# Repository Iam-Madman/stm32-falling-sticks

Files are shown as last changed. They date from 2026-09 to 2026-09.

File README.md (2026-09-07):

# stm32-falling-sticks

A DIY reaction-based "falling sticks" game controller built around an STM32 Bluepill.

## Features

- **STM32 Bluepill** as the main controller
- **10x electromagnet drivers (12v)** — MOSFET-switched, each with a flyback protection diode and pulldown resistor
- **10x Hall effect sensors (5v)** for stick drop/position detection
- **LCD output** support for game status/score
- **Buzzer (12v)** support, driven off the same MOSFET channels as the electromagnets
- **Start button** input to trigger the game
- **Single-layer PCB** — 0-ohm jumper resistors used in place of vias/second layer for a few connections
- **CNC-mill optimized** trace layout (tested on a Wegstr 3-axis CNC)

## Power

- Dual 12V input options: screw terminal or DC jack
- **MP1584EN buck converter** steps 12V down to 5V to power the electromagnets, Hall effect sensors, and Bluepill

## Board Previews

| View | Image |
| --- | --- |
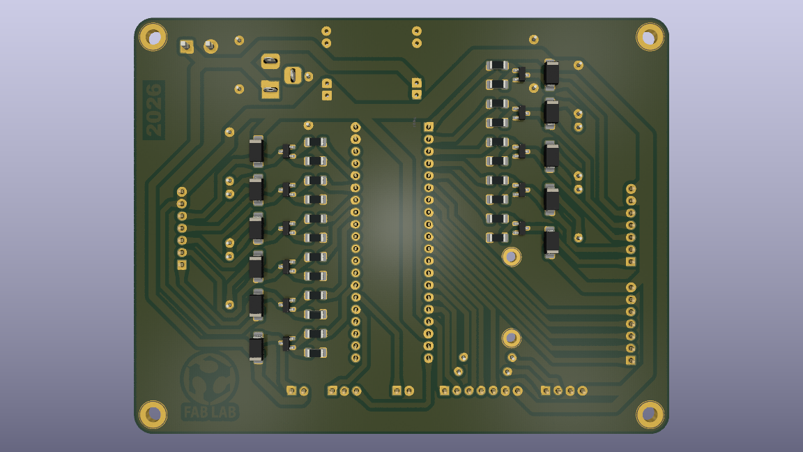
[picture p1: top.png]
Top View
| **Top View** |  |
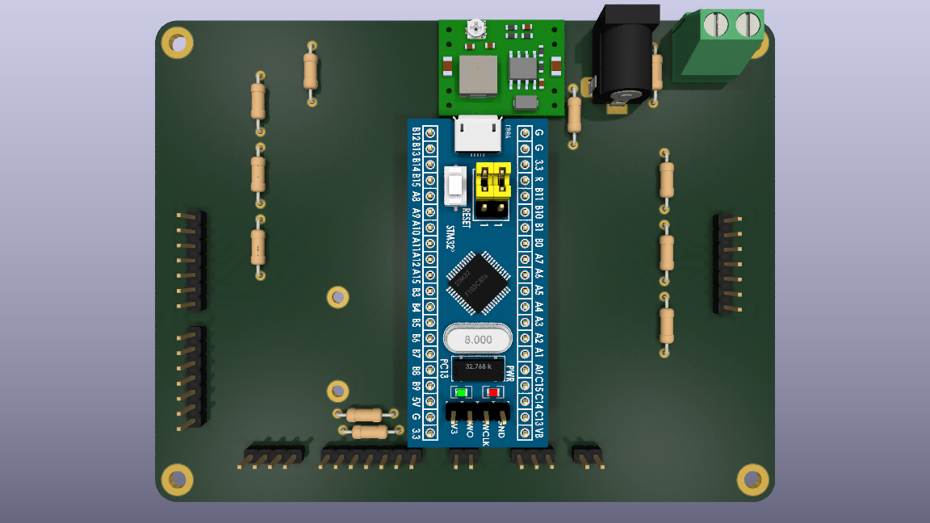
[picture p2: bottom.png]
Bottom View
| **Bottom View** |  |
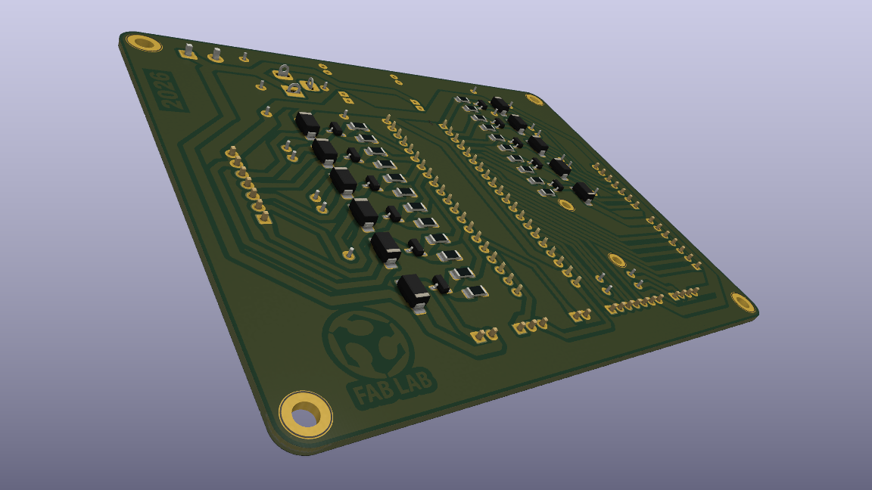
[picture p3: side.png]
Side View 1
| **Side View 1** |  |
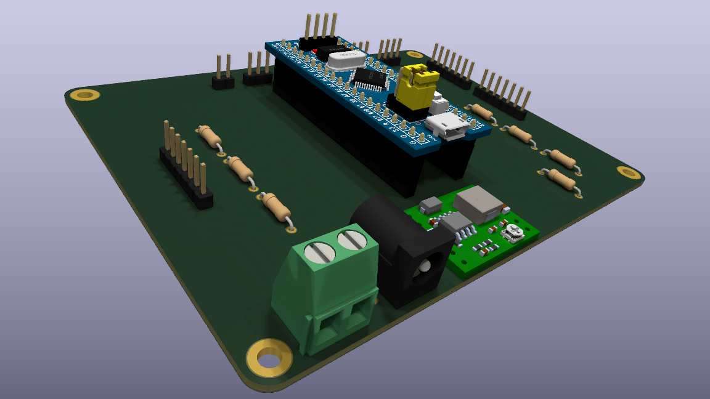
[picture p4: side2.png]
Side View 2
| **Side View 2** |  |

## Schematics
Schematic

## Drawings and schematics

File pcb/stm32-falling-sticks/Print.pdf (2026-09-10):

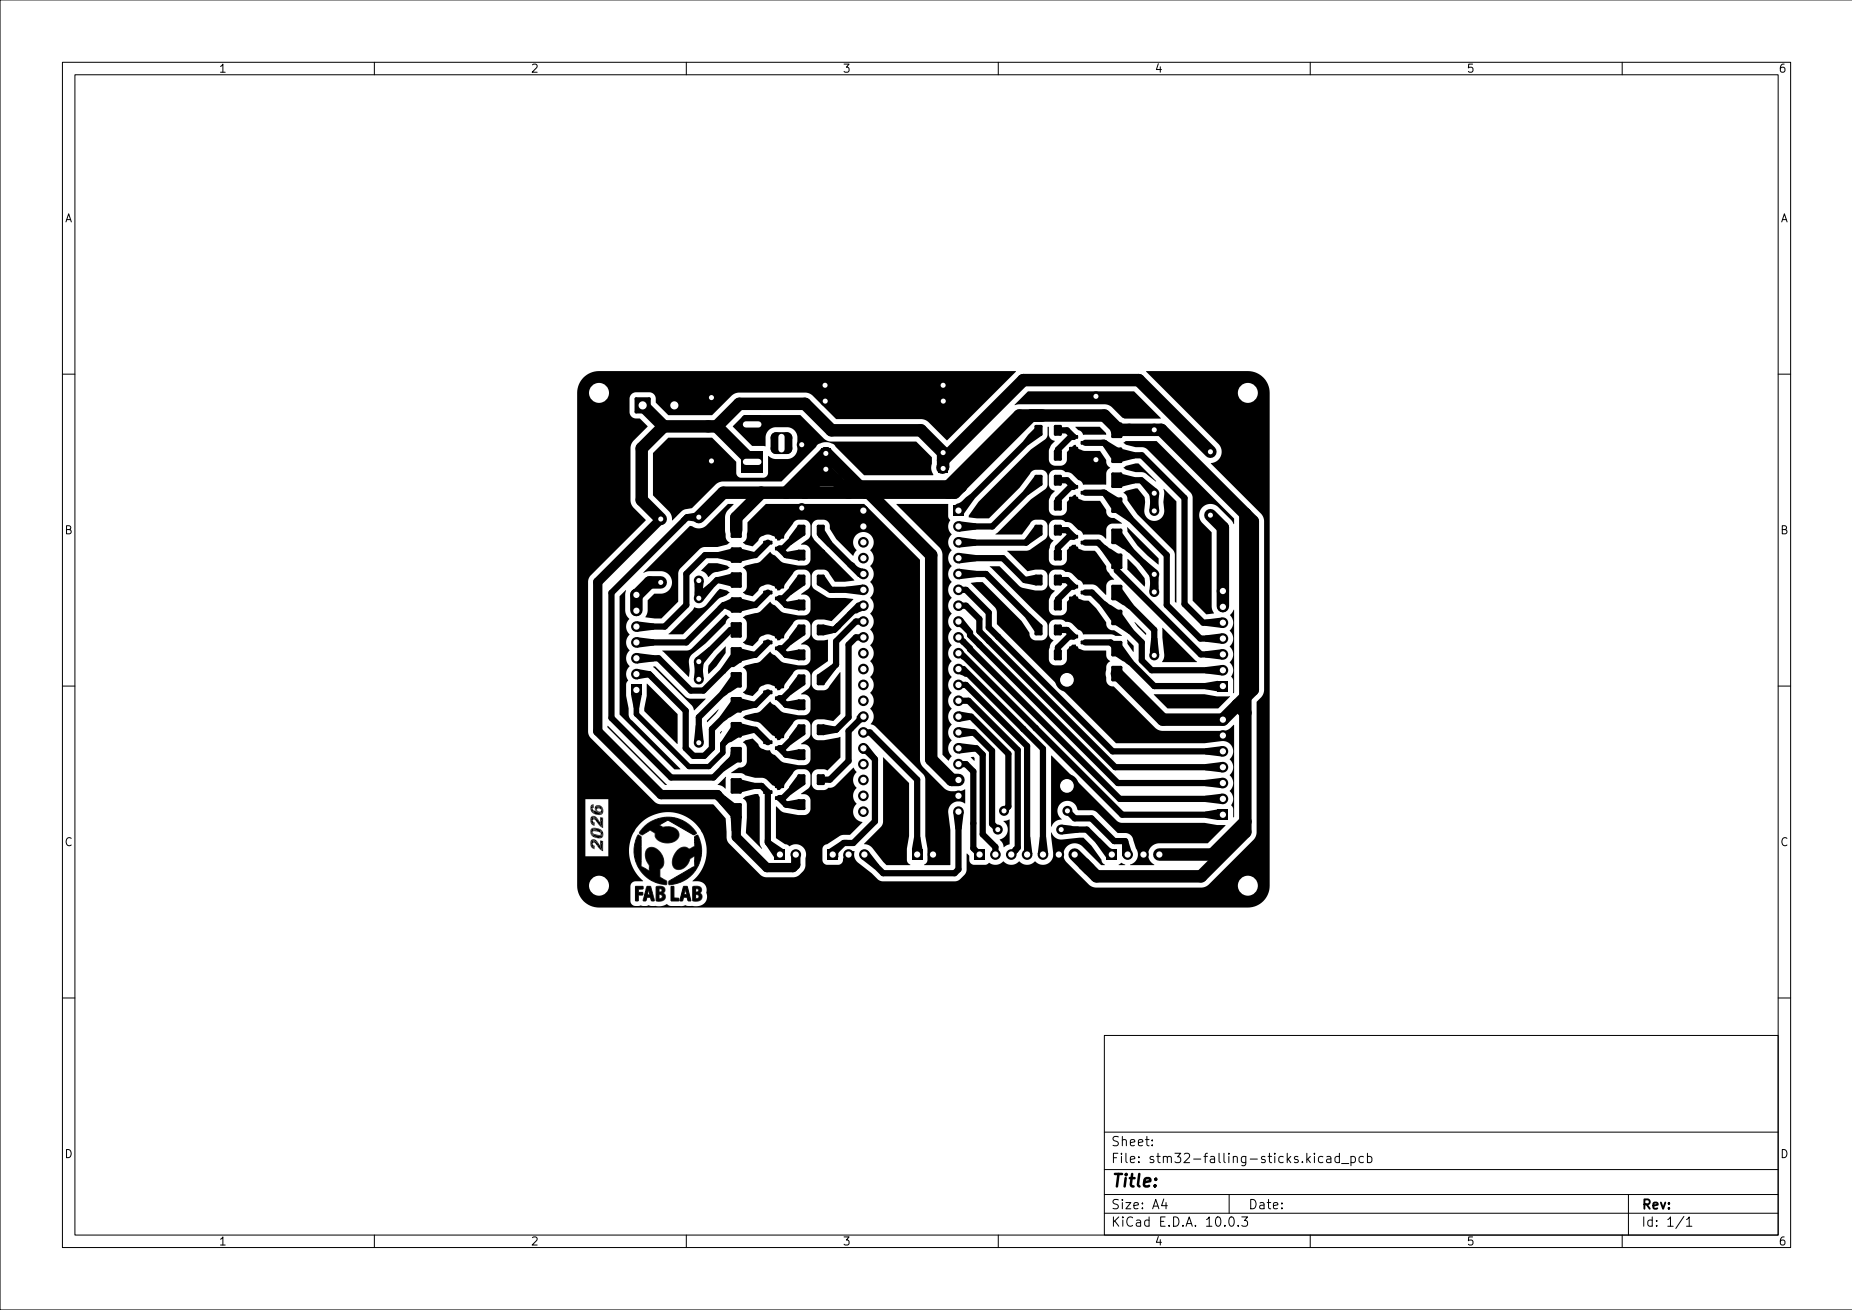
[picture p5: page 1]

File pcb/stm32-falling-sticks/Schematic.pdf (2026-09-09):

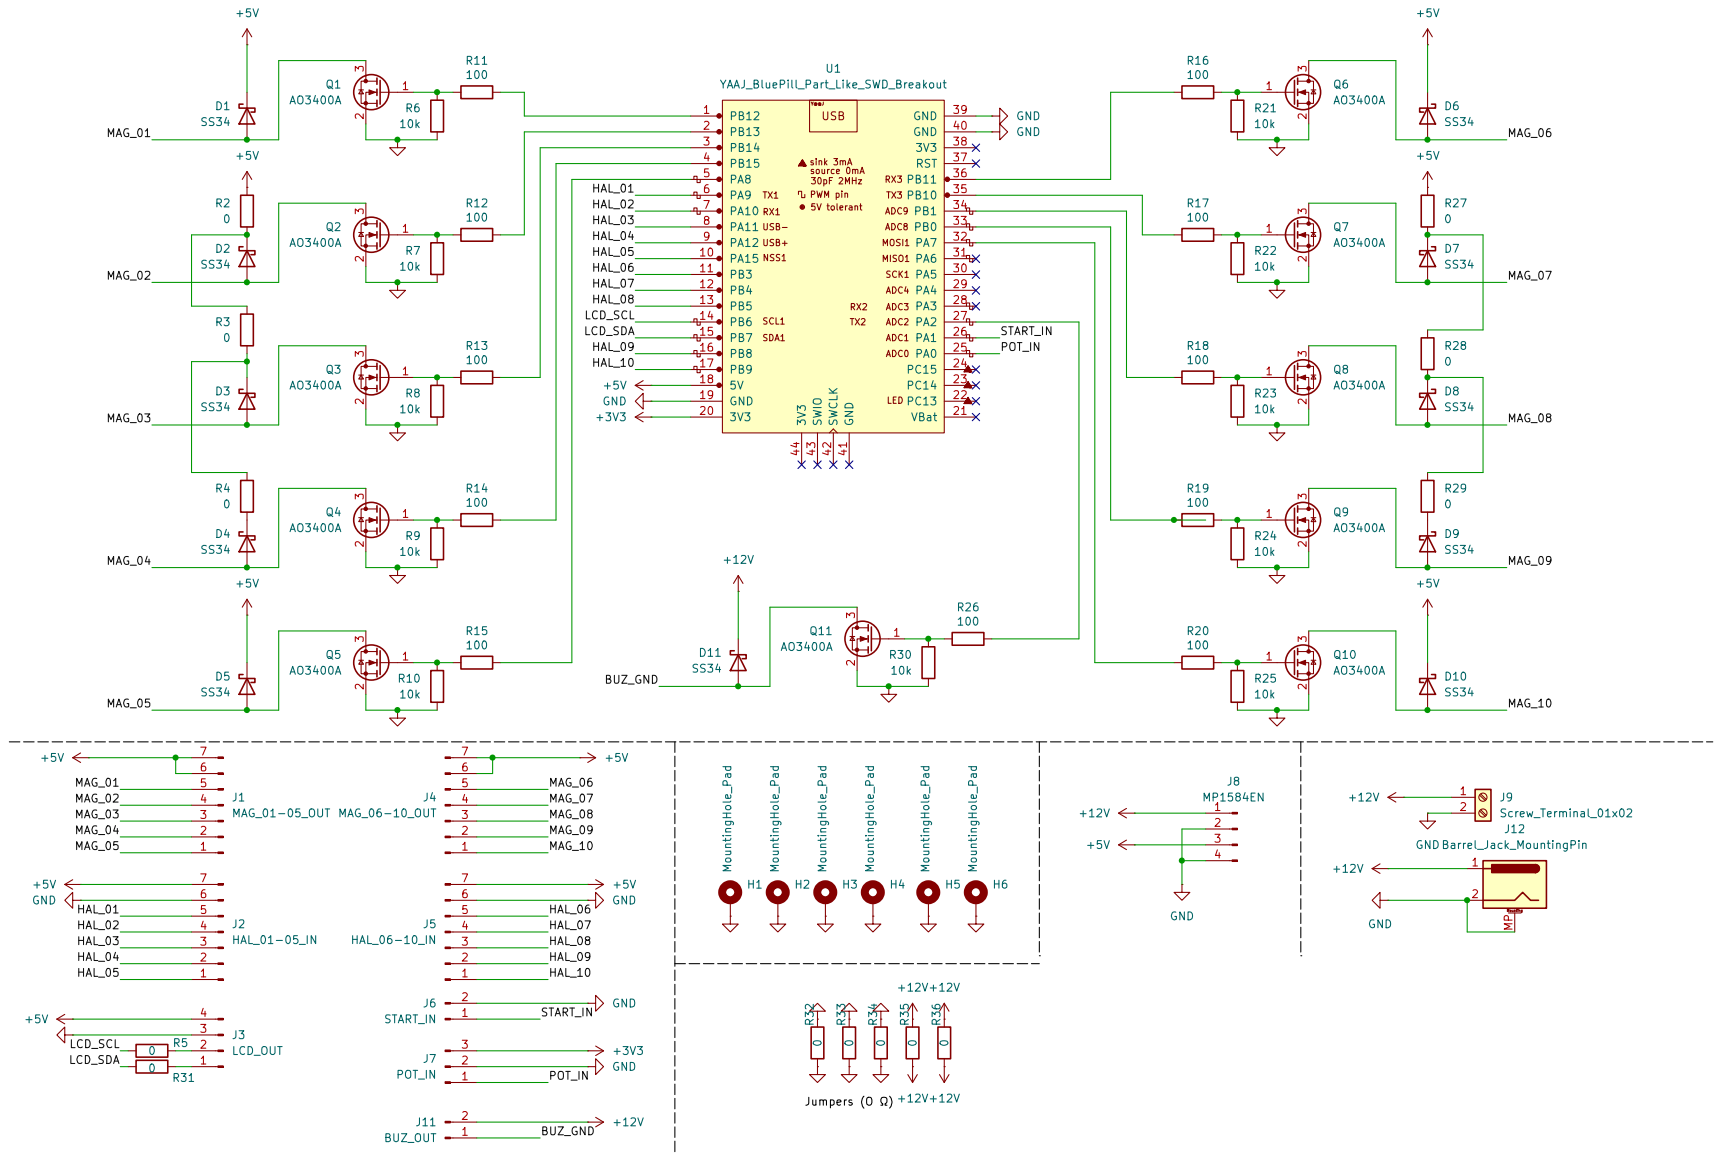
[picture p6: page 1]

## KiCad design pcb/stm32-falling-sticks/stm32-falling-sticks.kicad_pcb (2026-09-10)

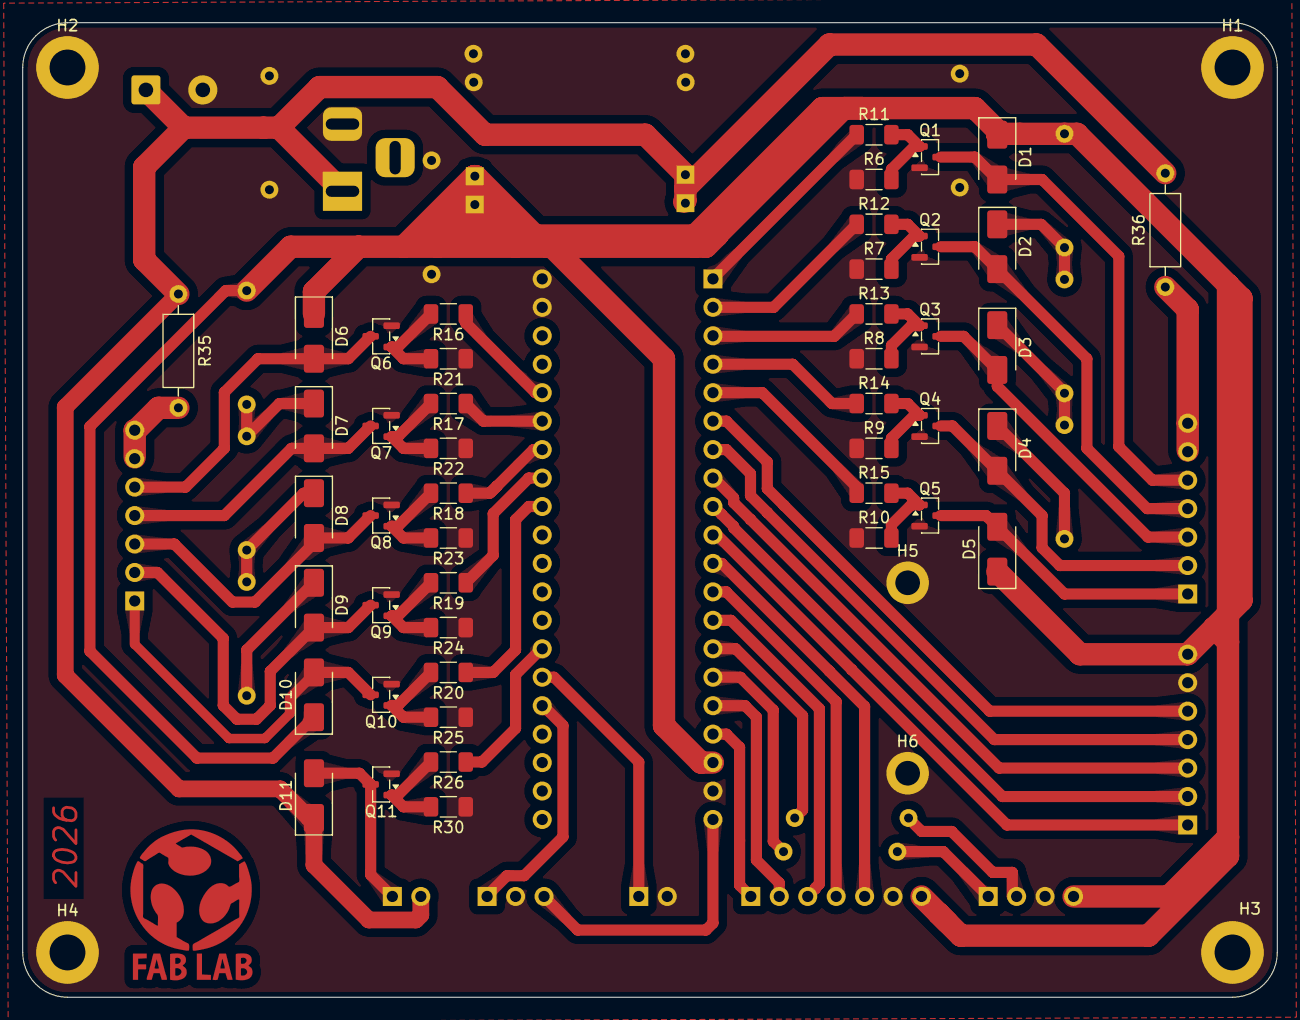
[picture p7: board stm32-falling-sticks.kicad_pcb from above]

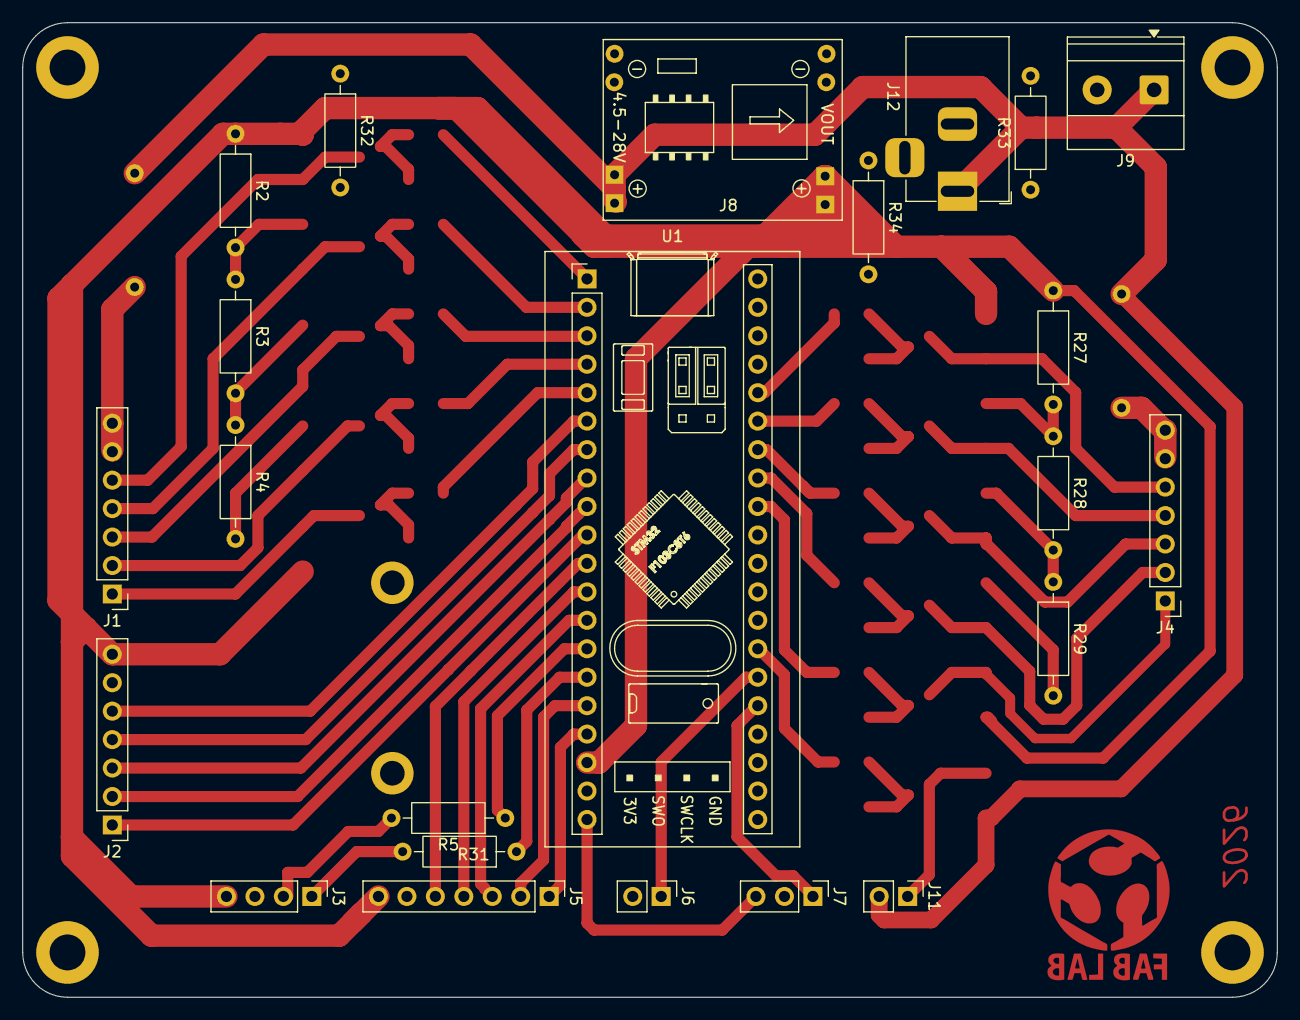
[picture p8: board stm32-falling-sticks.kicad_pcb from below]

Board: 2 copper layers, 112.0 x 87.0 mm, 75 parts (23 on the bottom side), 59 nets.

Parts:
D1, D2, D3, D4, D5, D6, D7, D8, D9, D10, D11: SS34; D_SMA
H1, H2, H3, H4: MountingHole_Pad; MountingHole_3.2mm_M3_DIN965_Pad
H5, H6: MountingHole_Pad; MountingHole_2.2mm_M2_DIN965_Pad
J1: MAG_01-05_OUT; PinHeader_1x07_P2.54mm_Vertical
J2: HAL_01-05_IN; PinHeader_1x07_P2.54mm_Vertical
J3: LCD_OUT; PinHeader_1x04_P2.54mm_Vertical
J4: MAG_06-10_OUT; PinHeader_1x07_P2.54mm_Vertical
J5: HAL_06-10_IN; PinHeader_1x07_P2.54mm_Vertical
J6: START_IN; PinHeader_1x02_P2.54mm_Vertical
J7: POT_IN; PinHeader_1x03_P2.54mm_Vertical
J8: MP1584EN; SRT_MPT1584EN_Module
J9: Screw_Terminal_01x02; TerminalBlock_Phoenix_MKDS-1,5-2-5.08_1x02_P5.08mm_Horizont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
J11: BUZ_OUT; PinHeader_1x02_P2.54mm_Vertical
J12: Barrel_Jack_MountingPin; BarrelJack_Horizontal
Q1, Q2, Q3, Q4, Q5, Q6, Q7, Q8, Q9, Q10, Q11: AO3400A; SOT-23
R2, R3, R4, R5, R27, R28, R29, R31, R32, R33, R34, R35, R36: 0; R_Axial_DIN0207_L6.3mm_D2.5mm_P10.16mm_Horizontal
R6, R7, R8, R9, R10, R21, R22, R23, R24, R25, R30: 10k; R_1206_3216Metric_Pad1.30x1.75mm_HandSolder
R11, R12, R13, R14, R15, R16, R17, R18, R19, R20, R26: 100; R_1206_3216Metric_Pad1.30x1.75mm_HandSolder
U1: YAAJ_BluePill_Part_Like_SWD_Breakout; YAAJ_BluePill_1

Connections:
+3V3: J7.3, U1.20 (3V3)
+5V: D1.1 (K), D5.1 (K), D6.1 (K), D10.1 (K), J2.7, J3.4, J5.7, J8.3, R2.1, R27.1, U1.18 (5V)
+12V: D11.1 (K), J1.6, J1.7, J4.6, J4.7, J8.1, J9.1, J11.2, J12.1, R35.1, R35.2, R36.1, R36.2
/BUZ_GND: D11.2 (A), J11.1, Q11.3 (D)
/HAL_01: J2.5, U1.6 (PA9)
/HAL_02: J2.4, U1.7 (PA10)
/HAL_03: J2.3, U1.8 (PA11)
/HAL_04: J2.2, U1.9 (PA12)
/HAL_05: J2.1, U1.10 (PA15)
/HAL_06: J5.5, U1.11 (PB3)
/HAL_07: J5.4, U1.12 (PB4)
/HAL_08: J5.3, U1.13 (PB5)
/HAL_09: J5.2, U1.16 (PB8)
/HAL_10: J5.1, U1.17 (PB9)
/LCD_SCL: R5.1, U1.14 (PB6)
/LCD_SDA: R31.1, U1.15 (PB7)
/MAG_01: D1.2 (A), J1.5, Q1.3 (D)
/MAG_02: D2.2 (A), J1.4, Q2.3 (D)
/MAG_03: D3.2 (A), J1.3, Q3.3 (D)
/MAG_04: D4.2 (A), J1.2, Q4.3 (D)
/MAG_05: D5.2 (A), J1.1, Q5.3 (D)
/MAG_06: D6.2 (A), J4.5, Q6.3 (D)
/MAG_07: D7.2 (A), J4.4, Q7.3 (D)
/MAG_08: D8.2 (A), J4.3, Q8.3 (D)
/MAG_09: D9.2 (A), J4.2, Q9.3 (D)
/MAG_10: D10.2 (A), J4.1, Q10.3 (D)
/POT_IN: J7.1, U1.25 (PA0)
/START_IN: J6.1, U1.26 (PA1)
GND: H1.1 (1_1), H2.1 (1_1), H3.1 (1_1), H4.1 (1_1), H5.1 (1_1), H6.1 (1_1), J2.6, J3.3, J5.6, J6.2, J7.2, J8.2, J8.4, J9.2, J12.2, Q1.2 (S), Q2.2 (S), Q3.2 (S), Q4.2 (S), Q5.2 (S), Q6.2 (S), Q7.2 (S), Q8.2 (S), Q9.2 (S), Q10.2 (S), Q11.2 (S), R6.1, R7.1, R8.1, R9.1, R10.1, R21.1, R22.1, R23.1, R24.1, R25.1, R30.1, R32.1, R32.2, R33.1, R33.2, R34.1, R34.2, U1.19 (GND), U1.39 (GND), U1.40 (GND)
unnamed: D2.1 (K), R2.2, R3.1
unnamed: D3.1 (K), R3.2, R4.1
unnamed: D4.1 (K), R4.2
unnamed: D7.1 (K), R27.2, R28.1
unnamed: D8.1 (K), R28.2, R29.1
unnamed: D9.1 (K), R29.2
unnamed: J3.1, R31.2
unnamed: J3.2, R5.2
unnamed: Q1.1 (G), R6.2, R11.2
unnamed: Q2.1 (G), R7.2, R12.2
unnamed: Q3.1 (G), R8.2, R13.2
unnamed: Q4.1 (G), R9.2, R14.2
unnamed: Q5.1 (G), R10.2, R15.2
unnamed: Q6.1 (G), R16.2, R21.2
unnamed: Q7.1 (G), R17.2, R22.2
unnamed: Q8.1 (G), R18.2, R23.2
unnamed: Q9.1 (G), R19.2, R24.2
unnamed: Q10.1 (G), R20.2, R25.2
unnamed: Q11.1 (G), R26.2, R30.2
unnamed: R26.1, U1.27 (PA2)
unnamed: R20.1, U1.32 (PA7)
unnamed: R15.1, U1.5 (PA8)
unnamed: R19.1, U1.33 (PB0)
unnamed: R18.1, U1.34 (PB1)
unnamed: R17.1, U1.35 (PB10)
unnamed: R16.1, U1.36 (PB11)
unnamed: R11.1, U1.1 (PB12)
unnamed: R12.1, U1.2 (PB13)
unnamed: R13.1, U1.3 (PB14)
unnamed: R14.1, U1.4 (PB15)

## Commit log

2026-09-06 refactor: prune unused KiCad 3D models and symbols, retain BluePill assets
    [stm32-falling-sticks.kicad_pcb, stm32-falling-sticks.kicad_sch]
2026-09-06 docs(updated_readme): updated readme description and included information about the schematics
2026-09-07 fix(Fixed_12v_tracks): Fixed 12v tracks for electromagnet
    [stm32-falling-sticks.kicad_pcb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]
2026-09-07 feat(solder_mask_expansion): improve solder mask expansion
    [stm32-falling-sticks.kicad_pcb]
2026-09-07 docs(fixed_typo): fixed the voltage values
2026-09-09 fix(jumper_fixes): jumper fixes
    [stm32-falling-sticks.kicad_pcb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]
2026-09-09 Changed 12v tracks to 5v
    [stm32-falling-sticks-B_Cu.gbr, stm32-falling-sticks-B_Mask.gbr, stm32-falling-sticks-Edge_Cuts.gbr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]
2026-09-10 docs(added_new_png): updated the rendering images of the pcb
2026-09-10 fix(Gerber_regenerated): Gerber_regenerated
    [stm32-falling-sticks.kicad_pcb, stm32-falling-sticks.kicad_sch]
2026-09-10 fix(Fixed_gerber): Fixed gerber
    [stm32-falling-sticks.kicad_pcb]
2026-09-10 fix(Gerber_fix): Gerber fix
    [stm32-falling-sticks-B_Cu.gbr, stm32-falling-sticks-B_Mask.gbr, stm32-falling-sticks-Edge_Cuts.gbr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]
